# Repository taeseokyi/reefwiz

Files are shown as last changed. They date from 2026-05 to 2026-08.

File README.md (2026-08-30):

# AquaWiz - 고정밀 pH/dKH 자동 측정 시스템

🌐 **실시간 측정 그래프:** https://taeseokyi.github.io/reefwiz/
(안드로이드 Chrome에서 열어 메뉴 → **홈 화면에 추가**를 누르면 앱처럼 설치됩니다)

> **:warning: 경고:** 이 프로젝트의 하드웨어, 소프트웨어, 문서는 **어떠한 공식 검증도 거치지 않았습니다.** 측정 정확도, 전기적 안전성, 장기 신뢰성에 대한 보증이 없으며, 사용으로 발생하는 모든 결과(장비 손상, 생물 피해, 화재, 감전 등)에 대한 **책임은 전적으로 사용자 본인**에게 있습니다.

산호 수조(리프 탱크)를 위한 Arduino Nano 기반 **자동 경도(dKH) 측정기**입니다.
탄산염 화학법을 이용하여 참조 해수와 수조수의 pH 차이로부터 dKH를 자동 산출합니다.

셋팅 구성

### 최종 형태 — 밀폐 폐루프 (공통 헤드스페이스)

> **밀폐는 선택이 아니라 필수입니다.** 참조수 통·측정 챔버·펌프 흡입을 **하나의 밀폐된 공기**로 묶어, 측정 순간 참조수(ref)와 수조수(tank)가 **같은 pCO₂**를 공유하도록 보장합니다. 이것이 방 CO₂ 변동을 차동으로 상쇄하는 핵심 조건이며, 동시에 증발(경도 농축)까지 차단합니다. 밀폐 적용 후 첫 새벽(고-CO₂) 측정에서 그간 재현되던 새벽 오차가 사라졌습니다(ΔpH −0.043 → **−0.008**) — [측정 대장](docs/measurement-ledger.md) 2026-06-19 참조.

| 제어기 |
|:---:|
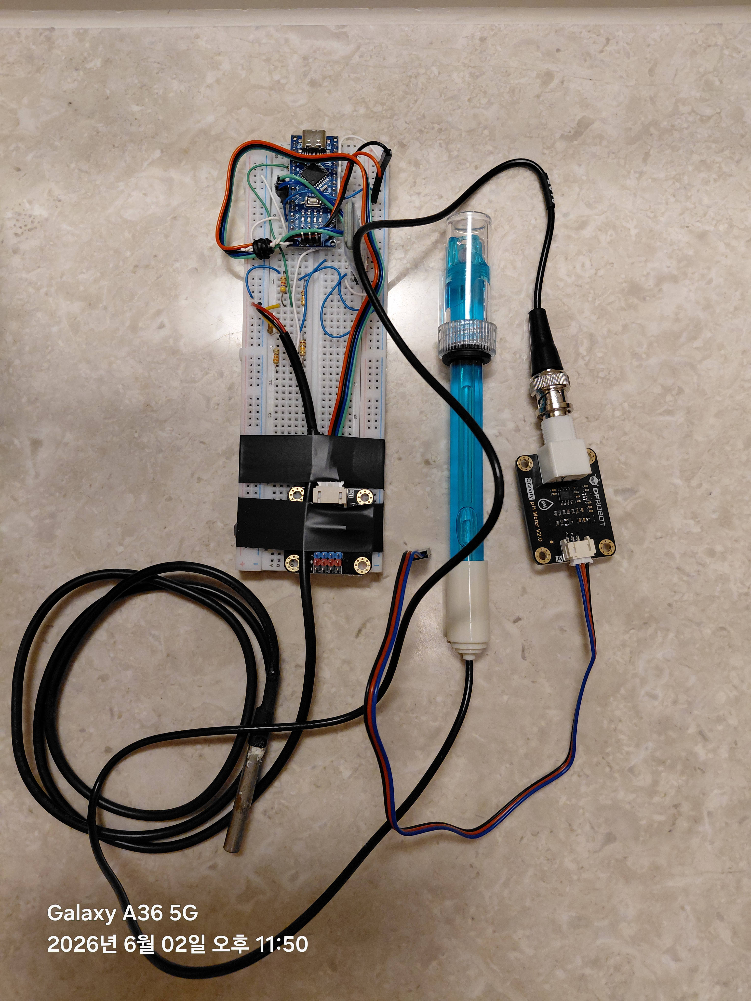
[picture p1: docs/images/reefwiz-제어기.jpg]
|  |

### 주요 특징

- **[±0.07 dKH 정확도](docs/system-setup.md#측정-정확도)** — 16비트 ADC + 64회 오버샘플링 + Nernst 온도 보정, 분해능 ±0.001 dKH
- **[PC 연동 평형 자동 측정](docs/system-setup.md#자동-측정-시퀀스-pc-측-v4)** — 샘플링 → 폭기(CO2 평형) → tank·ref **진짜 평형(평탄)까지** pH 측정 → dKH 계산 → 정리. 펌웨어가 아닌 PC측 파이썬 스크립트가 평탄(수렴) 판정으로 단계를 제어
- **[탄산염 화학법](#측정-원리)** — `KH_tank = KH_ref × 10^(-ΔpH)`, 참조수와 동시 탈기로 CO2 변수 제거
- **[Nernst 온도 보정](docs/system-setup.md#nernst-온도-보정)** — 보정 온도 EEPROM 저장, 15~35°C 전 범위 오차 0%
- **[블루투스 제어](docs/user-manual.md#14-블루투스-터미널-앱)** — HC-06으로 스마트폰에서 원격 제어/모니터링 ( <a href="https://play.google.com/store/apps/details?id=de.kai_morich.serial_bluetooth_terminal" target="_blank">Serial Bluetooth Terminal</a> 앱 추천)
- **[참조 dKH 역산](docs/user-manual.md#35-calref--참조-dkh-역산)** — 수조 dKH 실측값으로 참조수 dKH를 자동 계산, 참조수 별도 측정 불필요
- **[밀폐 공통 헤드스페이스 (필수)](docs/system-setup.md#위즈-탱크)** — 참조수·측정수·펌프 흡입이 한 밀폐 공기를 공유 → 측정 순간 ref·tank pCO₂ 일치(방 CO₂ 공통모드 상쇄) + 증발/오염 차단. 새벽 고-CO₂에서도 ΔpH 안정(2026-06-19 검증)
- **[3D 프린팅 하우징](docs/system-setup.md#하우징-3d-프린팅)** — OpenSCAD 파라메트릭 설계, 부품 실측 후 즉시 출력
- **[웹 대시보드 (PWA)](docs/user-manual.md#9-웹-대시보드)** — 측정 완료 직후 결과가 자동으로 GitHub Pages에 반영. dKH 그래프(3일/7일/전체), 평탄 수렴 곡선 조회(최근 14일), 최신값 JSON API
- **[도저 자동 조정 (권고)](docs/user-manual.md#10-도저-자동-조정-올포리프)** — 측정된 dKH 수준(3회 중앙값)·추세(7일 기울기)로 올포리프 도징량 조정을 계산. 대시보드에서 수동 도징량·목표 dKH 설정 가능
- **[reefCore 연동](docs/reefcore-integration.md)** — 측정값을 reefCore 생태계(reefChecker)에 측정 레코드로 발행(수동 도구 `bin/reefcore_bridge.py`. 측정 스크립트의 자동 발행은 2026-08-12 제거)
- **확장 가능** — ESP32 보드와 시리얼/블루투스 연결로 Wi-Fi, 모바일 앱, 인터넷 접속으로 확장 가능

> 정밀한 pH 측정을 위해 Wi-Fi가 없는 Arduino Nano를 사용하여 전자기 간섭을 최소화하였습니다. Wi-Fi, 웹 대시보드, 데이터 로깅 등 부족한 기능은 ESP32를 시리얼/블루투스로 연결하면 해결 가능합니다.

> 연동 펌프의 토출량은 설정한 시간(초)에 비례하지만, 호스 길이나 수두차에 따라 실제 물량이 달라질 수 있습니다. 각 펌프에 PWM 속도 컨트롤러의 Motor− 출력을 L298N ENA/ENB에 연결하여 역 PWM으로 모터 속도를 제어하므로, 토출량을 미세하게 조정할 수 있습니다.

## 한눈에 보기

| 시스템 구성도 | 호스 연결도 |
|:---:|:---:|
| 구성도 | 호스 |

| 회로도 (Fritzing) | 하우징 (3D 프린팅) |
|:---:|:---:|
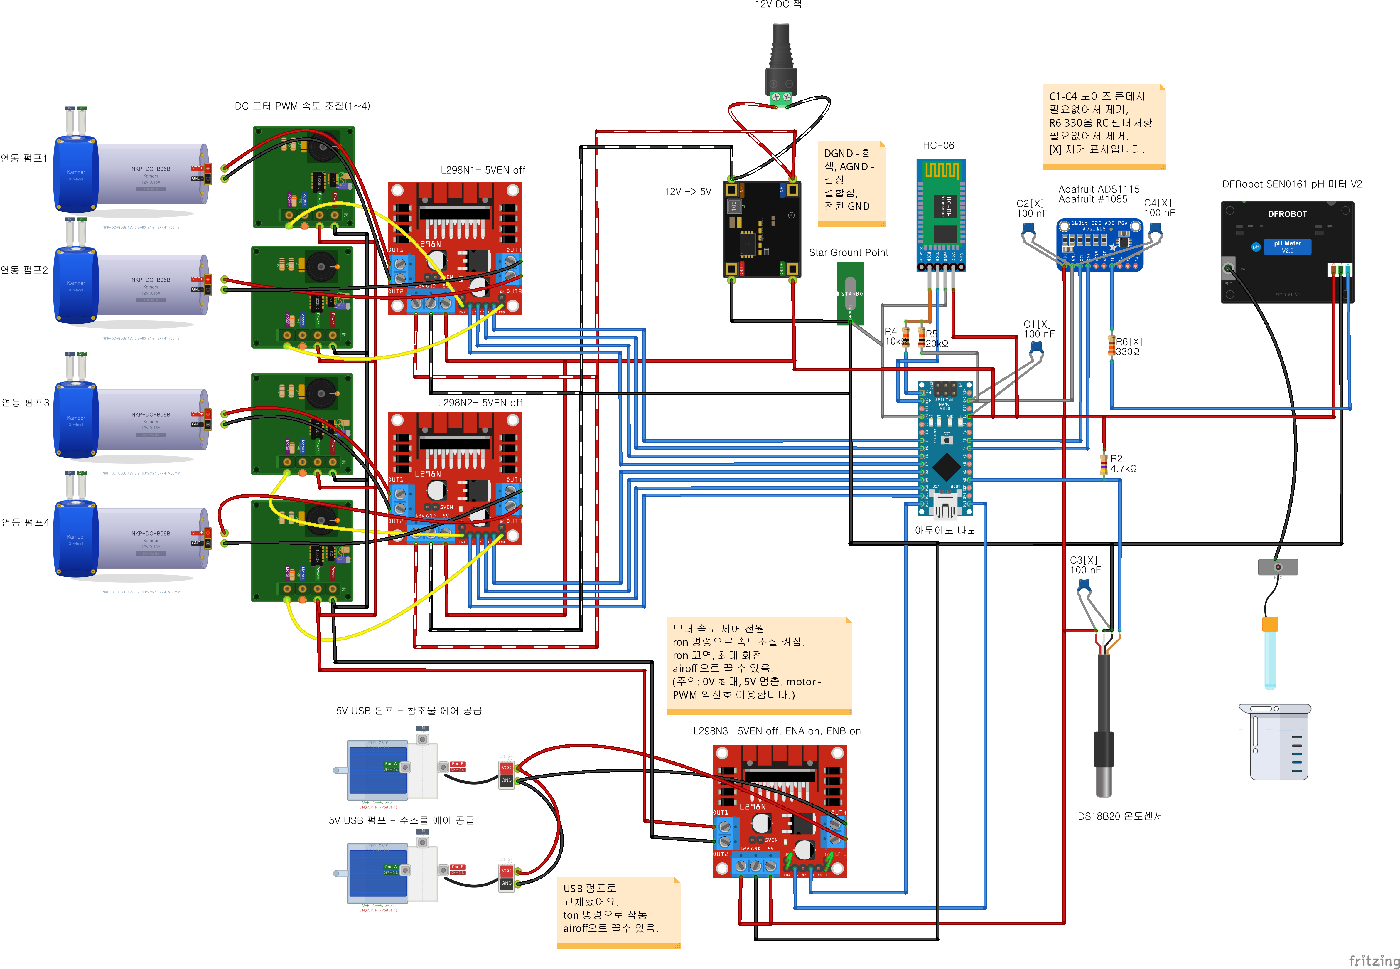
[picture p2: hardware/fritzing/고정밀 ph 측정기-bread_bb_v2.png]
회로도
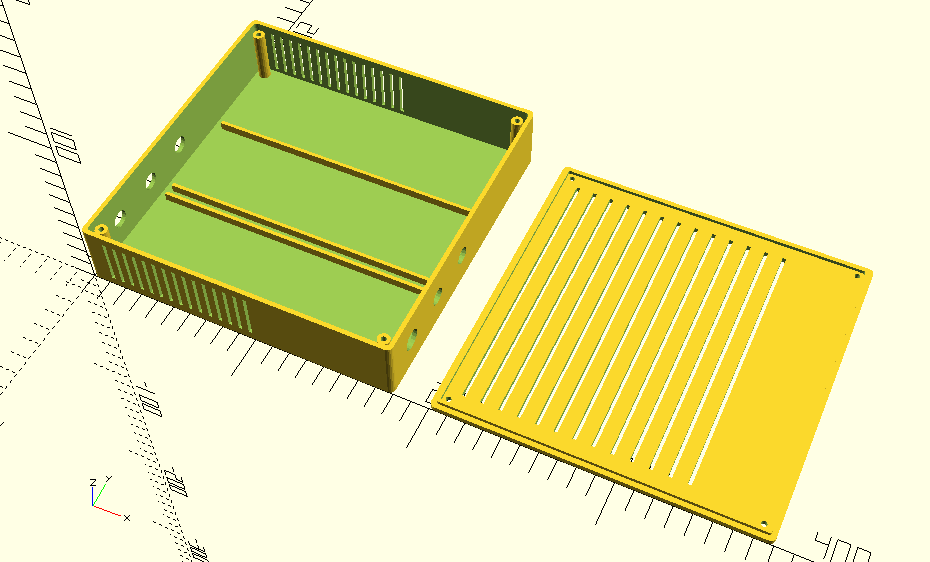
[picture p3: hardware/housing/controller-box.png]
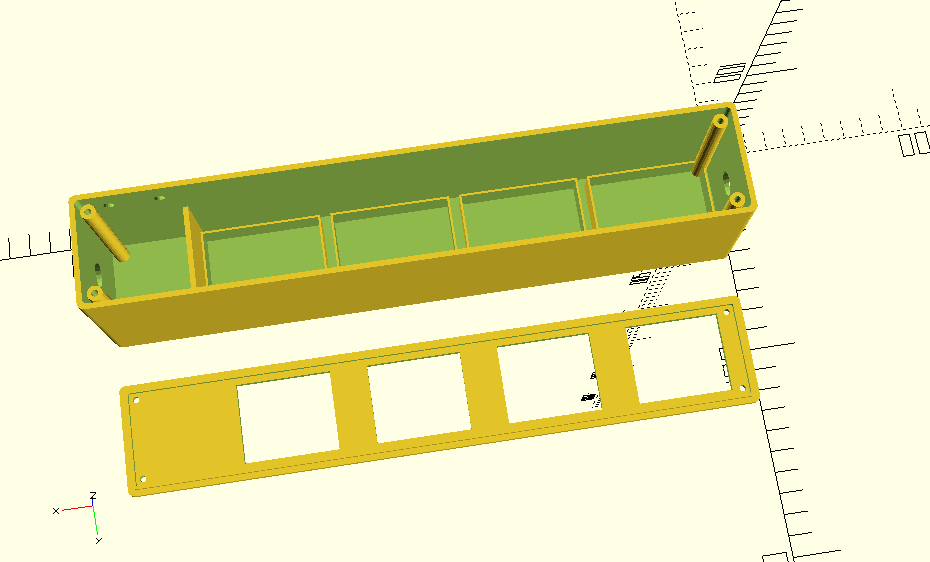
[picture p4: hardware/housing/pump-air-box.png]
펌프
|  |   |

## 측정 정확도

> **dKH 8.5 기준, 시스템 정확도 ±0.07 dKH (±1.2%)** — pH 프로브 반복성이 전체 오차의 97%를 차지하며, 전자 회로와 펌웨어 계산 로직은 프로브 성능을 100% 활용할 수 있는 수준입니다.

| 항목 | 성능 | 핵심 기술 |
|---|---|---|
| 측정 분해능 | **±0.001 dKH** | 16비트 ADC (ADS1115) + 64샘플 트림평균(정렬 후 상·하위 16개 버리고 중앙 32개 평균 → 폭기 버블 스파이크 제거) |
| 시스템 정확도 | **±0.07 dKH (±1.2%)** | Nernst 보정 + 동일 온도 차등 측정 |
| 온도 보정 오차 | **0%** | 보정 온도 EEPROM 저장, 15~35°C 전 범위 |

[상세 오차 분석 →](docs/system-setup.md#오차-요인-분석-dkh-85-기준)

> **이 수치는 책상 계산이 아니라 수십 회의 실측·검증을 거쳐 다듬은 결과입니다.** 코드 버전(V0~V4)별 측정 기록, 환경 변수(방 CO₂) 통제, 차동 측정이 방 CO₂ 의존성을 제거함을 보인 ΔpH 검증, 그리고 그 해석을 뒷받침한 학술 문헌까지 — 신뢰성의 근거는 모두 [**측정 대장**](docs/measurement-ledger.md)에 시각순으로 정리되어 있습니다.

> **✅ 완전 널테스트로 확정 (2026-06-21):** 같은 물(위즈 해수)을 ref·tank 양쪽에 넣어 *물 차이를 0으로 만든* 완전 널에서 **ΔpH −0.003, dKH 8.387 (참값 8.448 대비 오차 −0.061)** 을 측정했습니다. 물 차이가 구성상 0이므로 이 −0.06 dKH가 계측기의 *순수* 시스템 offset입니다 — ±0.07 정확도 사양을 실측으로 뒷받침합니다. (참고: 측정 시점에 보였던 큰 오차는 *시험용 옛 200mL 시료 물의 알칼리니티 손실(CaCO₃ 석출)* 이었으며 계측기 오차가 아니었습니다. 신선한 물에선 무보정으로 ±0.1 dKH 안.) — [측정 대장 최종 결론](docs/measurement-ledger.md) 참조.

## 측정 원리

```
KH_tank = KH_ref × 10^(-ΔpH)
ΔpH = pH_ref − pH_tank
```

탈기 후 두 샘플의 CO2 농도가 동일해지면, pH 차이는 순수하게 알칼리니티(dKH) 차이만을 반영합니다.

> **★전제 = 같은 pCO₂.** 위 식은 측정 순간 ref·tank의 CO₂가 동일할 때만 순수 dKH차를 줍니다. 이를 보장하는 것이 **밀폐 공통 헤드스페이스**입니다 — 두 물이 하나의 밀폐 공기를 공유하므로 방 CO₂가 변해도 공통모드로 상쇄됩니다. 밀폐는 [위즈 탱크 구성](docs/system-setup.md#위즈-탱크)에서 **필수**로 다룹니다.

## 하드웨어

| 부품 | 모델 | 역할 |
|---|---|---|
| MCU | Arduino Nano V3.0 (ATmega328P) | 메인 컨트롤러 |
| pH 센서 | DFRobot SEN0161-V2 | pH 전압 측정 |
| ADC | Adafruit ADS1115 (16-bit) | I2C 고정밀 ADC |
| 온도 센서 | DS18B20 (PTFE) | Nernst 온도 보상 |
| 블루투스 | HC-06 | 하드웨어 Serial (9600 baud) |
| 모터 드라이버 | L298N x 3 | L298N1/N2: 도징 펌프 (12V), L298N3: 에어 펌프 (5V) |
| 도징 펌프 | Kamoer NKP-DC-B06S x 4 | 참조수/수조수 도징 |
| 에어 펌프 | USB 5V 에어 펌프 x 2 | 참조수/수조수 폭기 (L298N3 제어) |
| 전원 | 12V DC + Buck Converter (5V) | 전원 공급 |

- 구매 링크 포함 상세 목록: [준비물 목록](docs/parts-list.md)
- 구성 요소 상세 / 펌프 역할: [자동화 환경 구성 — 구성 요소](docs/system-setup.md#구성-요소)
- 3D 프린팅 하우징: [자동화 환경 구성 — 하우징](docs/system-setup.md#하우징-3d-프린팅)

### 회로도

브레드보드 회로도

Fritzing 소스: <a href="hardware/fritzing/고정밀%20ph%20측정기-bread.fzz" target="_blank">고정밀 ph 측정기-bread.fzz</a> | PDF: <a href="hardware/fritzing/고정밀%20ph%20측정기-bread_bb.pdf" target="_blank">브레드보드 도면</a>

**핀 배치 요약:**

```
D0  (RX)  ← HC-06 TX        D1  (TX)  → HC-06 RX (전압분배기)
D4~D7     → L298N1 IN1~IN4  D8~D11    → L298N2 IN1~IN4
D12       → L298N3 IN2 (에어 펌프 ON/OFF, ron/roff)  D13  → L298N3 IN4 (PWM 속도 제어기 ON/OFF, ton/toff)
A0  (D14) ← DS18B20 DQ      A4/A5     ↔ ADS1115 I2C
```

### 전원 / 접지

```
12V DC Jack
  ├── L298N1, L298N2 (모터 전원, 12V → 도징 펌프)
  ├── Buck 12V→5V (Arduino, ADS1115, HC-06)
  └── USB 5V → L298N3 (에어 펌프 제어)
속도 제어: PWM 컨트롤러 Motor− → L298N ENA/ENB (역 PWM)
접지: Star Ground Point (DGND/AGND 분리 후 한 점 결합)
```

## 빌드 및 업로드

| 라이브러리 | 제작자 |
|---|---|
| DFRobot_PH | DFRobot |
| Adafruit ADS1X15 | Adafruit |
| OneWire | Paul Stoffregen |
| DallasTemperature | Miles Burton |

1. Arduino IDE에서 [`firmware/reefwiz_meter_m1/reefwiz_meter_m1.ino`](firmware/reefwiz_meter_m1/reefwiz_meter_m1.ino) 열기
2. 보드: **Arduino Nano**, 프로세서: **ATmega328P** 선택
3. **HC-06을 D0/D1에서 분리** 후 업로드 → 완료 후 재연결

## 사용 방법

### 초기 설정

```
1. pH 2점 보정:   enterph → calph (pH7) → exitph → enterph → calph (pH4) → exitph
2. 온도 오프셋:   settemp:-0.3
3. 참조 dKH:      setref:8.5
```

### 자동 측정 (PC 연동)

측정 전 고정 사전폭기(tank 25분·ref 3.5분)로 시료를 평형 근처까지 올린 뒤 **tank·ref가 진짜 평형(평탄)에 도달할 때까지** 반복 측정해야 하므로(평탄 판정 = 측정값 비교 후 반복 결정, 기포기 모터 노이즈 차단을 위해 각 read 직전에만 폭기를 끔), 자동화는 펌웨어가 아닌 **PC측 파이썬 스크립트**가 담당합니다. 펌웨어에는 더 이상 `seq` 매크로가 없습니다.

```bash
# 1회 측정 후 종료 (Windows 작업 스케줄러 정시 호출용 / 수동 실행 가능)
python bin/measure_kh_once.py        # 포트 미지정 시 bt_config.json 의 measure 포트 사용
python bin/measure_kh_once.py COM7   # 포트 직접 지정
```

스크립트는 준비(샘플링·헹굼) → **[A] tank 사전폭기(25분) + tank 평탄까지** → 전이 → **[B] ref 사전폭기(3.5분) + ref 평탄까지** → `calkh` → 정리 순으로 펌웨어 명령을 단계별 전송합니다. 상세 흐름·상수·스케줄러 등록은 [자동화 환경 구성 — 자동 측정 시퀀스](docs/system-setup.md#자동-측정-시퀀스-pc-측-v4)를 참조하세요.

### 주요 명령어

| 분류 | 명령어 |
|---|---|
| pH 측정 | `ref`, `tank`, `calkh`, `calref`, `status`, `khhist` |
| 식별 | `ver` (기기 버전 한 줄: `ReefWiz Meter M-1 v1.0.0 #커밋코드`) |
| pH 보정 | `enterph`, `calph`, `exitph` |
| 설정 | `settime:HH`, `setref:x`, `settemp:x` |
| 모터 | `m1f:초`, `m1b:초`, `m1s` (m1~m4) |
| 에어/PWM | `ron`/`roff` (D12 에어 ON/OFF), `ton`/`toff` (D13 PWM 제어기 ON/OFF), `airoff` (둘 다 OFF) |
| 정지 | `m1s`~`m4s` (개별), `stop` (전체 모터+핀 OFF) |

전체 명령어 및 상세 설명은 [사용 설명서](docs/user-manual.md)를 참조하세요.

## 문서

| 문서 | 설명 |
|---|---|
| [자동화 환경 구성](docs/system-setup.md) | 구성 요소, 호스 연결, 측정 시퀀스, 동기화 파이프라인, 하우징 |
| [사용 설명서](docs/user-manual.md) | 전체 명령어, 보정, 오류 메시지, 웹 대시보드, 도저 자동 조정 |
| [준비물 목록](docs/parts-list.md) | 부품 사진, 구매 링크, 금액 |
| [**측정 대장**](docs/measurement-ledger.md) | 코드 버전별 실측 기록·환경·ΔpH 검증·참조 문헌 — **결과 신뢰성의 근거** |
| [reefCore 연동](docs/reefcore-integration.md) | 측정값을 reefCore 생태계에 발행하는 MQTT 연동(수동 브리지) |
| [블루투스 재연결](docs/bt-reconnect-and-testing.md) | HC-06 RF 순단 대응·장기 사망 보강·시뮬레이터 회귀 검증 |

## 산호 수조 권장 dKH 범위

| 유형 | dKH |
|---|-----|
| 자연 해수 | 6.5 ~ 7.5 |
| 산호 수조 권장 | 8 ~ 12 |
| SPS 경산호 최적 | 8 ~ 9 |
| LPS/소프트 코랄 | 7 ~ 11 |

## 라이선스

이 프로젝트는 개인 용도로 제작되었습니다.

---

이 프로젝트의 펌웨어, 문서, 다이어그램, 하우징 설계의 **80% 이상이 AI의 도움**을 받아 작성되었습니다.

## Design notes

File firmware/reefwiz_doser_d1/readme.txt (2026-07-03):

L298N DC 모터 드라이버 - PWM 제어 하지 않음

상황 :   24V 전원에  6V 모터를 사용.   ENA, motor1, 오른쪽

“L298N 칩 자체는 ENA로 PWM 제어가 가능하지만,
시중 모듈 보드의 ENA 회로는 LED·저항이 RC 필터처럼 작동해 PWM 신호가 흐려집니다.
따라서 실제로는 IN1/IN2에 PWM을 걸어야 동작하며,
이때 BJT의 높은 포화전압과 24V 저듀티 구동으로 발열이 심해집니다.”

결론, PWM 을 쓰지 않고, L298N  출력쪽에 out1,out2 추가로 적정 볼륨형 PWM DC 모터 제어기를 추가 한다.

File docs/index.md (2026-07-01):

# AquaWiz

산호 수조용 고정밀 pH/dKH 자동 측정기 문서 모음입니다. 전체 개요는 [프로젝트 README](https://github.com/taeseokyi/reefwiz#readme)를 먼저 보세요.

## dKH 측정 대장 — 실시간 그래프

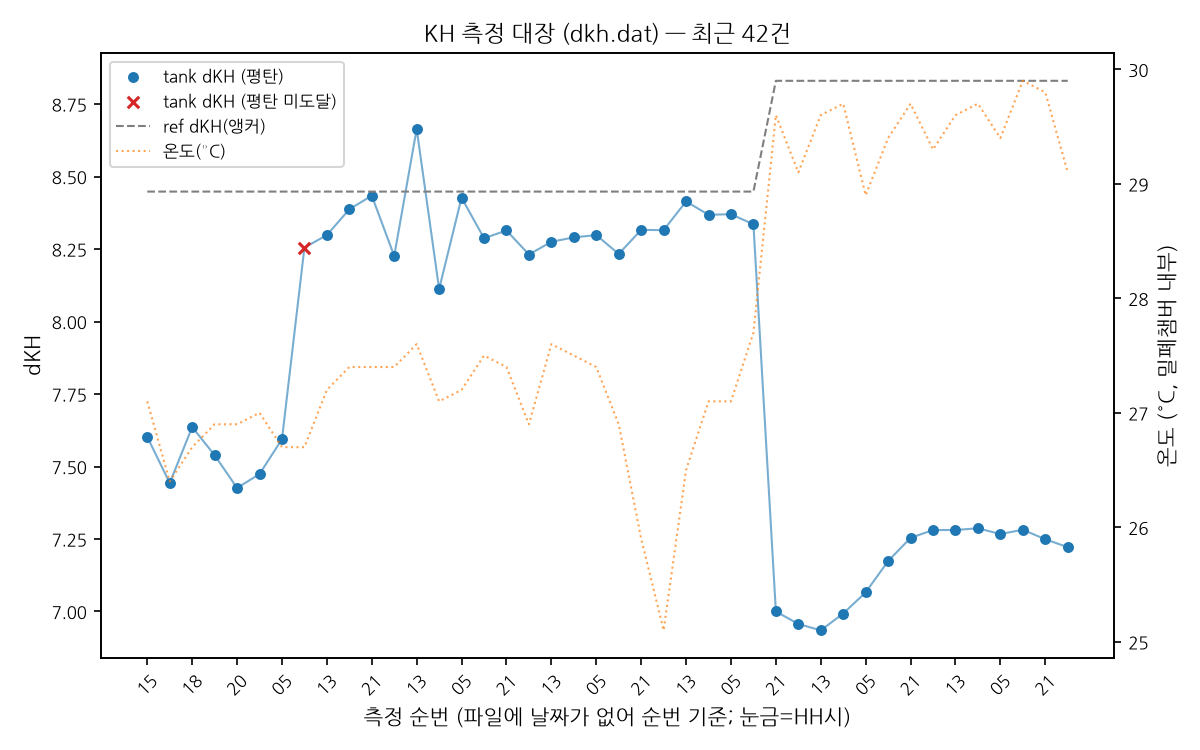
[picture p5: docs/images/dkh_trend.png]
dKH 추세


하루 3회(05/13/21시) 측정 결과가 자동으로 반영됩니다. 상세 기록·검증 근거는 [측정 대장](measurement-ledger.md)에 있습니다.

## 문서

- [측정 대장](measurement-ledger.md) — 코드 버전별 실측 기록·환경·ΔpH 검증·참조 문헌
- [사용 설명서](user-manual.md)
- [자동화 환경 구성](system-setup.md)
- [준비물 목록](parts-list.md)
- [reefCore 연동](reefcore-integration.md)
- [블루투스 재연결/테스트](bt-reconnect-and-testing.md)
- [연구 노트 모음](notes/README.md)

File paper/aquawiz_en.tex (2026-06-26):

\documentclass[11pt]{article}

% ---- arXiv-style preprint layout (pdflatex) ----
\usepackage[utf8]{inputenc}
\usepackage[T1]{fontenc}
\usepackage{lmodern}
\usepackage[margin=1in]{geometry}
\usepackage{amsmath,amssymb}
\usepackage{graphicx}
\usepackage{booktabs}
\usepackage{array}
\usepackage{multirow}
\usepackage{longtable}
\usepackage{caption}
\usepackage{authblk}
\usepackage{xcolor}
\usepackage{enumitem}
\usepackage[hidelinks]{hyperref}
\usepackage{textcomp}
\usepackage{mhchem}
\usepackage{siunitx}
\sisetup{detect-all}
\usepackage{pgfplots}
\pgfplotsset{compat=1.15}
\usetikzlibrary{arrows.meta,positioning,calc}

\captionsetup{font=small,labelfont=bf}
\renewcommand{\arraystretch}{1.15}

% convenience macros
\newcommand{\dpH}{\ensuremath{\Delta\mathrm{pH}}}
\newcommand{\dkh}{\ensuremath{\,\mathrm{dKH}}}
\newcommand{\co}{\ensuremath{\mathrm{CO_2}}}
\newcommand{\pco}{\ensuremath{p_{\mathrm{CO_2}}}}
\newcommand{\at}{\ensuremath{A_\mathrm{T}}}

\title{\bfseries A Low-Cost Single-Probe Differential-pH Aeration Monitor for\\
Seawater Carbonate Alkalinity: Systematic-Error Decomposition and\\
Sub-0.25\,dKH Accuracy via Sealed Common-Headspace Equilibration}

\author[1]{nowforyou\thanks{Correspondence: \texttt{taeseokyi@gmail.com}}}
\affil[1]{REEF FAMILY}

\date{\today}

\begin{document}
\maketitle

\begin{abstract}
\noindent
Carbonate alkalinity (``KH'', expressed in degrees, \dkh) is the single most
control-critical water-chemistry parameter in reef aquaria, yet affordable
continuous monitors are scarce and reagent titration is laborious. We describe
an open, reagent-free monitor that infers alkalinity from the equilibrium pH a
seawater sample reaches after aeration to atmospheric \co{}, using a
\emph{single} pH probe to measure an aquarium sample (``tank'') and a
known-alkalinity reference (``ref'') in immediate succession. Because dKH is
computed from the pH \emph{difference}
($\mathrm{KH_{tank}} = \mathrm{KH_{ref}}\cdot 10^{\dpH}$), absolute probe drift
and room-\co{} excursions are common-mode signals that cancel. Over a
nine-day instrumented campaign (30 logged measurements across five
firmware/method revisions) we observed a persistent uncorrected error of
$-0.92\dkh$ and, rather than zero-point calibrating it away, decomposed it.
Three interventions---(i) plateau-following measurement to true gas
equilibrium, (ii) a single \emph{sealed common headspace} shared by sample,
reference and pump intake, and (iii) an actively aerated 5\,L reference anchor
that pins the headspace \pco{}---collapsed the dawn-\co{} error and the
diurnal evaporation confound, and shrank measurement scatter to
$\mathrm{SD}=\pm0.08\dkh$ (about one-third of the $\pm0.25\dkh$ design goal). A
sequence of null experiments (identical water in both vessels, true
$\dpH=0$) then localized the residual: a \emph{complete null} returned
$\dpH=-0.003$, $\mathrm{dKH}=8.387$, i.e.\ an instrument offset of only
$-0.06\dkh$. The remaining $-0.86\dkh$ was traced to alkalinity loss
(\co{}\,driven \ce{CaCO3} precipitation / biofilm) in the days-old, small,
open tank aliquot---a sample-handling artifact, not a measurement fault.
Re-running the null on the same aged aliquot over the following day showed the
offset drifting away from zero ($-0.22$ then $+0.22\dkh$ on successive runs) with
the electronics untouched, confirming the attribution in the time domain.
The instrument therefore meets the $\pm0.25\dkh$ goal uncorrected, with
zero-point calibration deemed unnecessary. Our independently obtained error
structure (room-\co{} sensitivity, bubble-quality dependence, sealing as the
remedy) reproduces the published behaviour of a commercial counterpart, providing
external validation of both the diagnosis and the remedy.
\end{abstract}

\noindent\textbf{Keywords:} reef aquarium; carbonate alkalinity; total
alkalinity; \co{} equilibration; differential pH; low-cost instrumentation;
common-mode rejection; \ce{CaCO3} precipitation.

% =====================================================================
\section{Introduction}
% =====================================================================
Stony corals and other calcifying reef organisms deposit calcium carbonate at
a rate that continuously consumes carbonate alkalinity. In a closed reef
aquarium the resulting alkalinity drawdown is fast (often
$0.5$--$1.5\dkh\,\mathrm{day^{-1}}$) and swings of more than $\sim1\dkh$ are
implicated in coral tissue stress. Alkalinity (\at{}, conventionally reported
by hobbyists as ``KH'' in German degrees, $1\dkh \approx
0.357\,\mathrm{meq\,L^{-1}}$) is therefore the parameter most worth measuring
\emph{often}.

The accessible options are unsatisfying for continuous use. Manual reagent
titration (e.g.\ commercial drop kits) is accurate but labour-intensive and
discrete. Colorimetric robots automate titration but consume reagent and are
expensive. Direct potentiometric pH alone is \emph{not} an alkalinity measurement,
because seawater pH depends jointly on \at{} and \pco{}, and aquarium \pco{}
varies strongly over the day (room ventilation, photosynthesis, respiration).

A reagent-free alternative exploits the fact that if a sample is aerated until
its \pco{} equilibrates with the surrounding air, the equilibrium pH becomes a
single-valued function of alkalinity at fixed temperature and salinity. A
commercial product (AquaWiz) is built on this principle and is used by reef
hobbyists, but community reports document recurring inaccuracy tied to room-\co{}
fluctuation and to aeration/bubble quality. The contribution of this paper is
not the principle but a \emph{quantitative diagnosis}: starting from a working
DIY build, we conduct a nine-day instrumented campaign, expose a $-0.92\dkh$ raw error,
and show by construction (null experiments) that essentially all of it is a
sample-handling artifact rather than an instrument limitation---reducing the
true instrument offset to $-0.06\dkh$ and meeting a $\pm0.25\dkh$ goal without
calibration. Along the way we establish a small set of design rules (sealed
common headspace; plateau-following to true equilibrium; an actively aerated
reference anchor; a two-gate plateau criterion) that we expect to generalize to
any single-probe differential-pH alkalinity monitor.

% =====================================================================
\section{Measurement Principle}\label{sec:principle}
% =====================================================================

\subsection{Aeration makes equilibrium pH a proxy for alkalinity}
At fixed temperature $T$ and salinity $S$, the seawater carbonate system has
two degrees of freedom; fixing any two of
$\{\at{}, \mathrm{DIC}, \pco{}, \mathrm{pH}\}$ determines the rest. Aeration with
a large excess of room air drives the dissolved \co{} toward Henry's-law
equilibrium with the gas phase, $[\co{}]_{aq}=K_H\,\pco{}$, so that
$\pco{}(\mathrm{water}) \to \pco{}(\mathrm{air})$. Once \pco{} is clamped by the
atmosphere, the equilibrium pH is a single-valued function of alkalinity:
\begin{equation}
\mathrm{pH_{eq}} = f(\at{},\,\pco{},\,T,\,S).
\label{eq:pheq}
\end{equation}
With \pco{}, $T$, $S$ held common, the \emph{only} variable that can move
$\mathrm{pH_{eq}}$ is \at{}. Measured equilibrium pH is therefore a proxy for
alkalinity.

\subsection{Why the differential cancels room \co{}}
The instrument never relies on the absolute value of \pco{}. It aerates the
reference and the tank sample to the \emph{same} atmospheric ceiling (in the
final design, by aerating both against one shared headspace simultaneously,
Sec.~\ref{sec:methods}) and reports the \emph{difference} of their equilibrium
pH. Because the absolute \pco{} term is common to both samples, it cancels in
the difference: a room-\co{} excursion is a common-mode signal that drops out.
What survives the subtraction is the true alkalinity difference plus electrode
noise ($\pm0.005$--$0.01$\,pH). This is the central robustness argument of the
method, and the reason a \emph{single} probe (rather than two matched probes)
is used: a single sensor's slow asymmetry-potential and reference-junction
drift load identically onto both readings and cancel in \dpH{}.

\subsection{Over-aeration is impossible; only \emph{insufficient} aeration errs}
Equation~\eqref{eq:pheq} has a hard ceiling at $\pco{}(\mathrm{air})$: once the
water reaches atmospheric equilibrium, further aeration cannot raise pH. There
is consequently no ``over-aeration'' failure mode. Error enters only through
\emph{insufficiency}: if residual \co{} remains in one vessel, that side's pH is
unfairly depressed and a spurious \dpH{} appears. The differential's assumption
is precisely that ref and tank share the same \pco{}; broken symmetry breaks
the cancellation. This motivates measuring to a genuine plateau rather than for
a fixed time (Sec.~\ref{sec:methods}).

\subsection{Volume independence at full equilibrium}
Equation~\eqref{eq:pheq} contains no volume term (Henry's law is
intensive). Hence even a large volume mismatch---in our final null,
$100\,\mathrm{mL}$ of tank water against a $5\,\mathrm{L}$ reference---produces
\emph{zero} differential error provided both vessels reach \emph{full}
equilibrium. The familiar ``equal volumes for symmetry'' rule applies only
under \emph{partial} equilibration, where unequal volumes sit at different
points on the first-order approach curve
$C(t)-C^\ast = (C_0-C^\ast)\,e^{-t/\tau}$. The true requirements are just
(a) both fully equilibrated and (b) matched \pco{} and $T$. The larger volume
is rate-limiting, with a time constant
\begin{equation}
\tau \;\propto\; \frac{V}{K_H\,Q_\mathrm{gas}}\,\beta
\;\sim\; \frac{1}{\mathrm{VVM}}\,\beta,
\label{eq:tau}
\end{equation}
where $\mathrm{VVM}=Q_\mathrm{gas}/V$ is gas volume per liquid volume per
minute and $\beta$ is a seawater chemical factor (only trace
$[\co{}]_{aq}$ is strippable; the Revelle buffering raises $\tau$ by
$\sim8$--$15\times$). Equation~\eqref{eq:tau} is the basis for the
``increase aeration to shorten the measurement'' lever discussed later, and for
the choice to miniaturize the rate-limiting reference.

\subsection{The differential dKH formula}
The firmware (Arduino Nano / ATmega328P; pH via DFRobot Gravity probe + ADS1115
16-bit ADC) digitizes one probe, reading reference then tank pH, and computes
\begin{equation}
\boxed{\;\mathrm{KH_{tank}} \;=\; \mathrm{KH_{ref}}\cdot 10^{-(\mathrm{pH_{ref}}-\mathrm{pH_{tank}})}
\;=\; \mathrm{KH_{ref}}\cdot 10^{\dpH}\;}
\label{eq:dkh}
\end{equation}
with $\dpH \equiv \mathrm{pH_{tank}}-\mathrm{pH_{ref}}$ and
$\mathrm{KH_{ref}}=8.448\dkh$ an EEPROM-stored \emph{anchor} constant (set by a
\texttt{calref} command after evaporation top-off; \emph{not} a per-run
measurement---this is why the reference column reads a constant 8.448 in every
log line). Equation~\eqref{eq:dkh} depends only on \dpH{}; absolute pH cancels
exactly. Differentiating,
\begin{equation}
\frac{d\,\mathrm{KH_{tank}}}{d\,\dpH}\bigg|_{\dpH=0}
= \mathrm{KH_{ref}}\ln 10 \approx 19.45\;\dkh\,\mathrm{pH^{-1}},
\label{eq:sens}
\end{equation}
i.e.\ $0.01$\,pH of uncancelled difference maps to $\approx0.19\dkh$. This high
sensitivity is what makes both the cancellation and the plateau criterion
matter. Temperature compensation is applied per reading by a Nernst relation
$\mathrm{pH_{corr}}=7.0+(\mathrm{pH_{raw}}-7.0)\,(273.15+T_\mathrm{cal})/(273.15+T_\mathrm{meas})$,
nominally zero-error over 15--35\,\textcelsius. Each pH reading is a trimmed
mean of 64 samples (discard the top and bottom 16, average the middle 32) to
reject aeration-bubble spikes.

% =====================================================================
\section{Apparatus}\label{sec:apparatus}
% =====================================================================
The build (Table~\ref{tab:bom}, Fig.~\ref{fig:device}) is a closed fluidic loop
around four bidirectional peristaltic pumps, two USB air pumps, a single pH
probe, and a 1-Wire temperature sensor, all driven by an Arduino Nano over a
9600-baud Bluetooth (HC-06) serial link to a host PC.

\begin{figure}[t]
\centering
\begin{tikzpicture}[
  font=\footnotesize, >={Latex[length=1.8mm]},
  vessel/.style={draw, rounded corners=2pt, fill=blue!6, align=center},
  pump/.style={draw, circle, fill=yellow!35, font=\scriptsize\bfseries, inner sep=0.4pt, minimum size=5.5mm},
  flow/.style={<->, thick, blue!55!black},
  air/.style={-{Latex[length=1.6mm]}, densely dotted, red!65!black, thick},
  wire/.style={-{Latex[length=1.6mm]}, gray!55!black},
]
% sealed headspace
\draw[dashed, rounded corners=7pt, gray!65, line width=0.9pt] (0.1,-3.05) rectangle (10.9,1.95);
\node[anchor=north east, gray!55!black, font=\scriptsize] at (10.8,1.88) {Sealed common headspace ($\approx$4\,L)};
% controller (outside, top)
\node[draw, rounded corners=2pt, fill=gray!10, align=center] (mcu) at (4.9,2.75)
  {Arduino Nano $+$ HC-06\,/\,ADS1115 pH\,/\,DS18B20};
% vessels
\node[vessel, minimum width=15mm, minimum height=20mm, fill=cyan!10] (aq) at (-2.2,-0.6) {Main\\reef\\aquarium};
\node[vessel, minimum width=14mm, minimum height=14mm] (hold) at (1.9,0.7) {Holding};
\node[vessel, minimum width=21mm, minimum height=21mm] (meas) at (4.9,-0.7) {Measurement\\chamber};
\node[vessel, minimum width=16mm, minimum height=19mm] (ref) at (8.9,-0.4) {Reference\\1\,L\\\scriptsize($+T$ sensor)};
\node[vessel, minimum width=15mm, minimum height=11mm, fill=green!8] (kcl) at (4.9,-2.45) {3\,M KCl};
\node[draw, rounded corners=1pt, fill=red!9, font=\scriptsize, align=center] (airp) at (8.9,-2.45) {Air pumps (\texttt{ron})};
% pH probe
\draw[line width=1pt] ([xshift=-3mm]meas.north) -- ++(0,5mm) coordinate (pp);
\node[font=\scriptsize, anchor=south] at (pp) {pH probe};
% liquid flows with pumps
\draw[flow] (aq.east) -- (hold.west);
\node[pump] at ($(aq.east)!0.5!(hold.west)$) {M1};
\draw[flow] (hold.south) -- (meas.north west);
\node[pump] at ($(hold.south)!0.5!(meas.north west)$) {M2};
\draw[flow] (ref.west) -- (meas.east);
\node[pump] at ($(ref.west)!0.5!(meas.east)$) {M4};
\draw[flow] (kcl.north) -- (meas.south);
\node[pump] at ($(kcl.north)!0.5!(meas.south)$) {M3};
% air lines
\draw[air] (airp.north) -- (ref.south);
\draw[air] (airp.west) to[out=180,in=-90] (meas.south east);
% probe wire to controller
\draw[wire] (pp) to[out=90,in=-90] (mcu.south);
\end{tikzpicture}
\caption{Schematic of the sealed closed-loop monitor. A single pH probe in the
measurement chamber reads the tank aliquot and the reference in turn; four
bidirectional peristaltic pumps (M1--M4) move liquid between the main aquarium,
holding beaker, measurement chamber, reference reservoir, and KCl store; two air
pumps (\texttt{ron}) aerate the reference and the chamber simultaneously. The
reference, chambers and pump intakes share one sealed headspace ($\approx$4\,L),
so sample and reference see identical $p_{\mathrm{CO_2}}$ and evaporation is
suppressed; the controller sits outside. Between runs the probe rests in 3\,M
KCl (M3).}
\label{fig:device}
\end{figure}

\begin{table}[t]
\centering
\caption{Bill of materials (current build).}
\label{tab:bom}
\footnotesize
\begin{tabular}{@{}p{0.26\linewidth} p{0.50\linewidth} c@{}}
\toprule
Subsystem & Part & Qty \\
\midrule
Microcontroller & Arduino Nano V3.0 (ATmega328P) & 1 \\
pH probe & DFRobot Gravity pH V2 (SEN0161-V2), single glass electrode & 1 \\
ADC & DFRobot Gravity I\textsuperscript{2}C ADS1115 (16-bit) & 1 \\
Temperature & DS18B20 waterproof (1-Wire), in the 5\,L reference & 1 \\
Comms & HC-06 Bluetooth, 9600\,baud & 1 \\
Pumps & NKP-DC-B06B 12\,V peristaltic, bidirectional (M1--M4) & 4 \\
Motor drivers & L298 2\,A modules (2 for pumps, 1 for air) & 3 \\
Air pumps & USB 5\,V, switched together (\texttt{ron}) & 2 \\
Reference reservoir & 5\,L sealed container (``Wiz tank'') & 1 \\
Chambers & 200\,mL beakers: holding, measurement, 3\,M KCl & 3 \\
Probe storage & 3\,M KCl ($\approx$22\,\% w/v) & --- \\
\bottomrule
\end{tabular}
\end{table}

\paragraph{Fluidic topology (current).} All pumps are bidirectional
($\mathtt{f}$ = forward, $\mathtt{b}$ = reverse):
\begin{itemize}[nosep,leftmargin=1.4em]
\item \textbf{M1}: main aquarium $\leftrightarrow$ \emph{holding} beaker;
\item \textbf{M2}: holding $\leftrightarrow$ \emph{measurement} chamber;
\item \textbf{M3}: 3\,M KCl beaker $\leftrightarrow$ measurement chamber (probe soak / storage);
\item \textbf{M4}: 5\,L reference $\leftrightarrow$ measurement chamber.
\end{itemize}
Routing the tank sample through an intermediate holding beaker lets it be
temporarily \emph{parked} while the reference is measured, minimizing the
between-phase delay (Sec.~\ref{sec:methods}). Run times are encoded as the
integer in $\mathtt{mXf{:}NN}$ / $\mathtt{mXb{:}NN}$ (seconds); reverse runs
$\sim$8--10\,s longer than forward to fully clear the hose (current values
$\mathtt{m1f{:}70/m1b{:}82}$, $\mathtt{m2f{:}60/m2b{:}68}$,
$\mathtt{m3f{:}60/m3b{:}68}$, $\mathtt{m4f{:}60/m4b{:}70}$; the 5\,L hose is
longest, hence \texttt{m4b:70}).

\paragraph{Control commands.} Air and motor enables are independent lines:
\texttt{ron} turns \emph{both} air pumps on (used only while liquid is
stationary---bubble cleaning and measurement); \texttt{ton} enables the PWM
motor controller (\emph{required} before any pump will turn); \texttt{airoff}
drops both. A load-bearing invariant follows: because \texttt{airoff} also
disables the PWM controller, every liquid move must be preceded by
\texttt{airoff}\,$\rightarrow$\,\texttt{ton}; the last air command before a
motor must be \texttt{ton}. Measurement primitives are \texttt{tank} / \texttt{ref}
(sample and store one pH reading) and \texttt{calkh} (apply
Eq.~\eqref{eq:dkh}).

\paragraph{Sealed common headspace (required).} The 5\,L reference, the
measurement chamber, and the pump intake share \emph{one} sealed headspace.
This is not an optional refinement: it (i) guarantees tank and ref see identical
\pco{} at the instant of measurement (the differential's premise), (ii) blocks
room-\co{} excursions at the source, and (iii) suppresses evaporation. In the
final configuration the headspace is $\approx$4\,L, the reference $\approx$1\,L,
and the tank aliquot $100\,\mathrm{mL}$; an air stone placed \emph{in} the
reference actively pins the shared \pco{} within minutes (the
``anchor'', Sec.~\ref{sec:methods}). Separate or isolated headspaces are
explicitly forbidden---two headspaces drift independently and destroy the
cancellation.

% =====================================================================
\section{Methods}\label{sec:methods}
% =====================================================================

\subsection{Two-phase plateau-following cycle (V4)}
Plateau detection is a host-side decision loop, so the PC script drives the
firmware step by step. The cycle measures \textbf{tank first, then ref}, so the
5\,L reference is co-aerated throughout the tank phase and converges quickly
when its turn comes:
\begin{enumerate}[nosep,leftmargin=1.6em]
\item \emph{Prep:} \texttt{m3b} (drain KCl from chamber)
$\rightarrow$ \texttt{m1f} (aquarium $\to$ holding)
$\rightarrow$ \texttt{m2f} (holding $\to$ chamber).
\item \emph{Phase A:} \texttt{ron}; measure \texttt{tank} every 30\,s until
plateau (chamber tank + 5\,L aerated together).
\item \emph{Transition:} \texttt{m2b} parks the tank aliquot back in holding;
\texttt{m4f} brings reference into the chamber.
\item \emph{Phase B:} \texttt{ron}; measure \texttt{ref} until plateau
(fast---already near equilibrium).
\item \texttt{calkh}; then cleanup: \texttt{m4b} (recover ref to 5\,L),
\texttt{m1b} (return parked tank to aquarium), \texttt{m3f} (restore KCl soak),
\texttt{airoff} (probe rests in KCl).
\end{enumerate}

\subsection{Two-gate plateau criterion}
Readings are held as integer milli-pH (mpH) to avoid floating-point boundary
jitter. A plateau is declared only when \emph{both} gates hold over a sliding
window (Table~\ref{tab:plateau}): a short \emph{span} gate (last 4 readings,
$\mathrm{max}-\mathrm{min}\le 2$\,mpH) rejects noise, and a longer \emph{net}
gate (last 8 readings, $|w_{-1}-w_{0}|\le 1$\,mpH) rejects a slow monotonic
exponential tail that the span gate alone would mistake for convergence. The
longer net look-back (8 vs.\ 4 points; ``B1'') was the fix for early latches in
which the tank stopped climbing prematurely. Per-phase wall-clock and
read-count caps ($\mathtt{PHASE\_MAX}=7200\,\mathrm{s}$,
$\mathtt{MEAS\_MAX}=240$) and a consecutive-failure cap
($\mathtt{FAIL\_MAX}=5$) bound the loop so it can never hang.

\begin{table}[t]
\centering
\caption{Plateau-following parameters (\texttt{measure\_until\_flat}).}
\label{tab:plateau}
\footnotesize
\begin{tabular}{@{}llp{0.5\linewidth}@{}}
\toprule
Constant & Value & Meaning \\
\midrule
\texttt{FLAT\_SPAN\_N}  & 4 & span window (jitter gate) \\
\texttt{FLAT\_SPAN\_MPH}& 2 & last 4: $\max-\min\le 2$\,mpH \\
\texttt{FLAT\_NET\_N}   & 8 & net look-back (drift gate; B1) \\
\texttt{FLAT\_NET\_MPH} & 1 & last 8: $|w_{-1}-w_0|\le 1$\,mpH \\
\texttt{MEAS\_INTERVAL} & 30\,s & between readings (aeration continuous) \\
\texttt{PHASE\_MAX\_SECS}& 7200\,s & per-phase cap (2\,h; 4\,h total) \\
\texttt{MEAS\_MAX}      & 240 & per-phase read cap \\
\texttt{FAIL\_MAX}      & 5 & consecutive parse failures tolerated \\
\bottomrule
\end{tabular}
\end{table}

Figure~\ref{fig:plateau} shows a measured pair of approach curves. The tank,
freshly drawn into the chamber, climbs a slow first-order tail toward its
ceiling and is held by the net gate until it is genuinely flat (latching at
$\sim$624\,s when the 8-point net drift falls to 1\,mpH). The reference, having
co-aerated in the 5\,L reservoir throughout the tank phase, is already at
equilibrium and latches in $\sim$2.6\,min---a direct illustration of why
measuring tank-first is faster, and of why the span gate alone (satisfied near
$\sim$546\,s) would have latched the tank early.

\begin{figure}[t]
\centering
\begin{tikzpicture}
\begin{axis}[
  width=0.86\linewidth, height=6.2cm,
  xlabel={Elapsed time (s)}, ylabel={pH (equilibrium approach)},
  xmin=-20,xmax=660, ymin=7.825, ymax=7.915,
  grid=both, major grid style={gray!18}, minor grid style={gray!8},
  legend style={at={(0.63,0.55)},anchor=center, fill=white, fill opacity=0.85,
    text opacity=1, draw=gray!40, font=\footnotesize}, legend cell align=left,
  tick label style={font=\footnotesize}, label style={font=\small},
]
\addplot[blue!70!black, mark=*, mark size=1.1pt, thick] coordinates {
(0,7.829)(38,7.832)(77,7.834)(116,7.836)(156,7.838)(195,7.840)(234,7.841)
(273,7.843)(312,7.844)(351,7.845)(390,7.846)(429,7.847)(468,7.848)(507,7.849)
(546,7.849)(585,7.850)(624,7.850)};
\addlegendentry{tank (chamber sample)}
\addplot[red!75!black, mark=square*, mark size=1.1pt, thick, dashed] coordinates {
(0,7.906)(38,7.909)(77,7.909)(117,7.909)(156,7.909)};
\addlegendentry{ref (co-aerated 5\,L)}
\node[anchor=west,font=\scriptsize,blue!50!black] at (axis cs:430,7.843) {net-gate latch @624\,s};
\draw[blue!50!black,->,>=stealth] (axis cs:560,7.844) -- (axis cs:620,7.849);
\end{axis}
\end{tikzpicture}
\caption{Measured plateau-following curves (sealed, net-gate run). The tank
sample (solid) climbs a slow exponential tail and is latched only when the
two-gate criterion (last-4 span $\le 2$\,mpH \emph{and} last-8 net $\le 1$\,mpH)
is met; the co-aerated reference (dashed) is already near equilibrium and latches
quickly. The two series sit at different pH because the underlying samples differ
(this run predates the null campaign); only their respective \emph{plateau}
values enter Eq.~\eqref{eq:dkh}.}
\label{fig:plateau}
\end{figure}

\subsection{Logging and fault handling}
Each completed run appends one line
\texttt{HH ref\_pH tank\_pH 8.448 tank\_kh temp} to \texttt{dkh.dat}. Two
distinct markers encode abnormal outcomes: an \emph{all-zeros} line on hard
failure (timeout, serial loss, or unverified KCl soak), which additionally
\emph{latches}---a subsequent run refuses to measure and re-writes the marker
until a human clears it, protecting the probe from unattended pump cycling; and
a \emph{negative} \texttt{tank\_kh} (magnitude preserved, sign flipped) when a
phase hits its cap without reaching plateau, which the data server reads as
``did-not-plateau'' but which does \emph{not} trip the latch. A \texttt{finally}
block runs an emergency cleanup (air off, drain chamber, restore KCl soak) on
any non-completion.

\subsection{Null-test protocol}
The diagnostic backbone is the \emph{null test}: the reference and tank vessels
are filled with the \emph{same} water so the true alkalinity difference is zero
and the correct output is exactly $\dpH=0$, $\mathrm{dKH}=8.448$. Two variants
are used. In a \emph{partial null}, only the small tank aliquot is replaced with
fresh seawater while the aged 5\,L reference is retained, so a change in \dpH{}
isolates the tank water's contribution. In a \emph{complete null}, reference
water is also placed in the tank chamber, so the water difference is zero
\emph{by construction} and any residual \dpH{} is purely instrumental.

\subsection{Revision history and the one-change-at-a-time rule}
The build evolved through five revisions (Table~\ref{tab:versions}). Changes
were made one causal axis at a time, so that each measurement campaign tests a
single mechanism; where two constants were changed together
(e.g.\ stabilization window and convergence band), they were justified as the
\emph{same} causal axis (response completeness), not two independent variables.

\begin{table}[t]
\centering
\caption{Method/firmware revisions. ``ron held'' = continuous aeration between runs.}
\label{tab:versions}
\footnotesize
\begin{tabular}{@{}llp{0.56\linewidth}@{}}
\toprule
Rev & Period & Change vs.\ prior \\
\midrule
V0 & 6/14--6/15 & First symmetric build; reference drawn from 5\,L into a cup; fixed 1200\,s aeration. \\
V1 & 6/15--6/16 & Added continuous aeration between runs (\texttt{ron} held). \\
V2 & 6/16--6/17 & Reference taken as a small directly-aerated aliquot (holding $\to$ chamber); aeration off during the reading. \\
V3 & 6/17 & Aeration \emph{during} measurement (pin tank/ref to same \pco{}); path symmetrized; KCl-rinse bubble clean (later dropped). \\
V4 & 6/17$\to$ & \textbf{Plateau-following} to true equilibrium (no fixed time); two-phase tank-then-ref; anti-hang caps; emergency cleanup. Subsequently: \emph{sealed common headspace}, \emph{5\,L active anchor}, and the two-gate (B1) criterion. \\
\bottomrule
\end{tabular}
\end{table}

% =====================================================================
\section{Results}\label{sec:results}
% =====================================================================
Table~\ref{tab:data} lists the full campaign. Throughout, $\dpH<0$ means the
tank read more acidic than the reference (lower apparent alkalinity), and by
Eq.~\eqref{eq:dkh} the raw error is
$\mathrm{dKH}-8.448 = 8.448\,(10^{\dpH}-1)$.

{\scriptsize\setlength{\tabcolsep}{4pt}
\begin{longtable}{@{}r l l r r r r r p{0.30\linewidth}@{}}
\caption{Complete measurement campaign (30 runs). ``abs pH'' is the common-mode
level (a room-\co{} proxy within a single day only). Config abbreviations:
S = sealed headspace, A = 5\,L active anchor, N = net-gate, B1 = net look-back 8.
\textbf{Null staging:} a fresh seawater batch is aliquoted at the start; PN =
partial null (the $100\,\mathrm{mL}$ tank chamber alone is refilled with that
fresh aliquot while the aged $5\,\mathrm{L}$ reference is kept, isolating the
tank-water contribution); CN = complete null (reference water is then transferred
into the tank chamber as well, so both vessels hold \emph{identical} water and the
water difference is zero by construction).}
\label{tab:data}\\
\toprule
\# & Date/time & Cfg & pH$_\mathrm{ref}$ & pH$_\mathrm{tank}$ & \dpH{} & dKH & $T$ & Conditions \\
\midrule
\endfirsthead
\multicolumn{9}{l}{\scriptsize\emph{Table~\ref{tab:data} (continued)}}\\
\toprule
\# & Date/time & Cfg & pH$_\mathrm{ref}$ & pH$_\mathrm{tank}$ & \dpH{} & dKH & $T$ & Conditions \\
\midrule
\endhead
\midrule
\multicolumn{9}{r}{\scriptsize\emph{continued on next page}}\\
\endfoot
\bottomrule
\endlastfoot
1 & 06-14 20:12 & V0 & 7.959 & 8.021 & $+0.062$ & 9.741 & 26.7 & first manual symmetric run \\
2 & 06-14 21:00 & V0 & 7.997 & 8.072 & $+0.075$ & 10.054& 26.2 & --- \\
3 & 06-15 05:00 & V0 & 8.057 & 8.077 & $+0.020$ & 8.843 & 26.4 & dawn but $+$; window open (ventilated), low \co{} \\
4 & 06-15 13:00 & V1 & 8.050 & 8.042 & $-0.008$ & 8.293 & 27.0 & first continuous aeration \\
5 & 06-15 21:00 & V1 & 8.109 & 8.091 & $-0.018$ & 8.109 & 27.3 & clean low-\co{} point \\
6 & 06-16 05:00 & V1 & 7.810 & 7.751 & $-0.059$ & 7.362 & 27.5 & dawn closed-room \co{} spike (both abs pH fell $\sim$0.3) \\
7 & 06-16 13:00 & V1b& 8.091 & 8.063 & $-0.028$ & 7.922 & 27.7 & tighter window/band \\
-- & 06-16 21:00 & --- & \multicolumn{5}{c}{\emph{failed (0.000; power cut, port semaphore)}} & \\
8 & 06-16 21:21 & V2 & 8.042 & 8.021 & $-0.021$ & 8.039 & 28.6 & first V2 (manual) \\
9 & 06-17 05:00 & V2 & 7.997 & 7.939 & $-0.058$ & 7.386 & 27.8 & V2 dawn test \emph{failed}; regressed to V1 \\
10& 06-17 13:00 & V3 & 8.109 & 8.091 & $-0.018$ & 8.095 & 28.2 & first V3; ref under-equilibrated (5 reads) \\
11& 06-17 21:00 & V4 & 8.113 & 8.071 & $-0.042$ & 7.669 & 27.8 & first V4 + trim-mean firmware; clean plateaus \\
12& 06-18 05:00 & V4 & 7.738 & 7.695 & $-0.043$ & 7.657 & 28.2 & \textbf{decisive:} dawn $-0.043\approx$ evening $-0.042$ despite 0.4 abs-pH swing $\Rightarrow$ \co{}-level independence \\
13& 06-18 13:00 & V4 & 8.081 & 8.055 & $-0.026$ & 7.950 & 28.3 & same low \co{} as \#11 yet $-0.026$; dKH $+0.29$ jump $\Rightarrow$ baseline \emph{not} constant (evaporation, open 200\,mL day 5) \\
14& 06-19 05:00 & V4+S & 7.976 & 7.968 & $-0.008$ & 8.283 & 28.1 & \textbf{seal verif.\,\textcircled{1}}: dawn dip collapses $-0.05\!\to\!-0.008$; plateau 33$\to$4 reads \\
15& 06-19 13:00 & V4+S & 7.957 & 7.947 & $-0.010$ & 8.255 & 28.6 & \textbf{seal verif.\,\textcircled{2}}: dawn$\to$noon jump $+0.29\!\to\!-0.03$ ($\sim$10$\times$); evaporation removed \\
16& 06-19 21:00 & V4+S & 7.969 & 7.968 & $-0.001$ & 8.421 & 26.8 & near-perfect null (raw err $-0.027$, smallest); but $+0.166$ vs.\ \#14/15 $\Rightarrow$ offset not a perfect constant; AC transient ($-1.8$\,\textcelsius) \\
17& 06-20 05:00 & V4+S & 7.922 & 7.871 & $-0.051$ & 7.521 & 27.7 & dawn dip recurs; tank 11$\times$ monotone = early latch (not true plateau); AC cooling slowed kinetics \\
18& 06-20 15:00 & V4+SAN& 7.975 & 7.929 & $-0.046$ & 7.602 & 27.1 & first 5\,L anchor; tank \emph{true} plateau (34$\times$, 21.6\,min) yet $-0.046$ $\Rightarrow$ \textbf{genuine gap}, not latch artifact \\
19& 06-20 18:11 & V4+S,2$\times$& 7.979 & 7.924 & $-0.055$ & 7.443 & 26.4 & controlled exp; 2$\times$ aeration halves climb (1296$\to$711\,s) but \dpH{} unchanged $\Rightarrow$ \emph{not} kinetics \\
20& 06-20 18:57 & V4+S,2$\times$& 7.975 & 7.931 & $-0.044$ & 7.636 & 26.7 & ref-first + hose swap; gap persists $\Rightarrow$ order/path/non-equilibrium all rejected \\
21& 06-20 19:50 & V4+S & 7.975 & 7.926 & $-0.049$ & 7.539 & 26.9 & reproduction \\
22& 06-20 20:29 & V4+SA& 7.977 & 7.921 & $-0.056$ & 7.426 & 26.9 & tank-first+park; ref fastest ever (4$\times$); tank early latch (7.921) $\Rightarrow$ motivates B1 \\
23& 06-20 21:00 & V4+SA,B1& 7.979 & 7.926 & $-0.053$ & 7.474 & 27.0 & \textbf{B1 ok}: tank 25$\times$/945\,s true plateau; confirms \#22 was $\sim$5\,mpH short; gap (7th) \\
24& 06-21 05:00 & V4+SA,B1& 7.974 & 7.928 & $-0.046$ & 7.594 & 26.7 & dawn matches evening cluster $\Rightarrow$ time-of-day dependence ruled out (gap, 8th) \\
25& 06-21 06:00 & V4+S,PN& 7.973 & 7.963 & $-0.010$ & $-8.255$ & 26.7 & \textbf{partial null}: fresh tank only; tank pH $+37$\,mpH, \dpH{} $-0.05\!\to\!-0.010$; tank not plateaued (old cap) $\Rightarrow$ lower bound \\
26& 06-21 13:00 & V4+S,PN& 7.964 & 7.956 & $-0.008$ & 8.298 & 27.2 & \textbf{partial null, full eq.}: dKH 8.298, raw err $-0.15$; back in good cluster; 4\,h cap validated \\
27& 06-21 19:00 & V4+S,CN& 7.960 & 7.957 & $-0.003$ & 8.387 & 27.4 & \textbf{complete null}: reference water into tank chamber too $\Rightarrow$ both identical; raw err $-0.061$ = pure instrument offset; $100\,$mL vs.\ 5\,L cancels \\
28& 06-21 21:00 & V4+S,CN& 7.959 & 7.958 & $-0.001$ & 8.434 & 27.4 & \textbf{complete null} (2nd): $\dpH-0.001$ (resolution limit), raw err $-0.014$ (smallest); reconfirms the $\le0.06\dkh$ offset \\
-- & 06-22 05:00 & V4+S,CN & \multicolumn{5}{c}{\emph{failed (cap)}} & 55-min scheduler cap killed it mid-ref; tank had plateaued (7.955); fix: 5\,h cap \\
29& 06-22 09:00 & V4+S,CN& 7.959 & 7.948 & $-0.011$ & 8.226 & 27.4 & \textbf{aged complete null} ($\sim$14\,h, $100\,\mathrm{mL}$ exposed aliquot): null decayed to raw err $-0.22$; tank true plateau 59$\times$ (long aeration drives precipitation, KH$\downarrow$) \\
30& 06-22 13:00 & V4+S,CN& 7.950 & 7.961 & $+0.011$ & 8.664 & 27.6 & \textbf{aged null reverses} ($\sim$18\,h): short plateau (tank 8$\times$), $\dpH>0$, dKH $8.664$ (raw err $+0.22$) $\Rightarrow$ evaporative concentration (KH$\uparrow$) overtakes precipitation \\
\bottomrule
\end{longtable}
}

\subsection{The dawn-\co{} error and its diagnosis}
The earliest clear pathology was a dawn collapse of \dpH{} (run \#6,
$-0.059$; error $-1.09\dkh$). The decisive clue was common mode: \emph{both}
absolute pH values fell $\sim0.3$ overnight (ref $8.109\!\to\!7.810$, tank
$8.091\!\to\!7.751$), reversing the daytime upward trend---the signature of a
closed-room \co{} build-up acidifying the aeration water. A natural experiment
confirmed it: on the one ventilated night (run \#3, window open) the absolute
pH stayed high and \dpH{} was a normal $+0.020$, whereas closed nights gave
$-0.058/-0.059$. Crucially, room \co{} is exactly the common-mode variable the
differential is \emph{supposed} to cancel; its leakage into \dpH{} signalled a
broken ref/tank symmetry, not an environmental problem to be ventilated away.

\subsection{Plateau-following and the inter-phase drift conflict}
Measuring to a true plateau (V4) removed the \co{}-\emph{level} dependence: runs
\#11/\#12 gave $\dpH=-0.042$ and $-0.043$ across a 0.4-unit swing in absolute
pH. But the first V4 run had exposed a competing failure: a 31-minute tank
measurement whose pH rose to a peak then \emph{fell} (room \co{} drifting during
the measurement), latching at a value set by whenever the single probe happened
to sample each vessel. This \emph{inter-phase drift}, of order
\begin{equation}
\epsilon_\mathrm{drift} \;\approx\; \Delta t_{\mathrm{tank{-}ref}}\times \frac{dC}{dt},
\label{eq:drift}
\end{equation}
sets up a fundamental conflict with a single probe: full equilibrium needs long
measurements, but long measurements widen the tank--ref sampling gap
$\Delta t$ and thus the drift. The same form with $dT/dt$ explains run \#16,
where an air-conditioner cooling overshoot ($-1.8$\,\textcelsius{} during the
run) coincided with a $+0.166\dkh$ excursion.

\subsection{Sealing collapses both confounds}
A single \emph{sealed common headspace} resolves the conflict at the source. By
compelling the reference and tank to share a single common air volume, it makes
the common \pco{} intrinsic rather than coincidental, blocks room-\co{}
excursions, and additionally suppresses the evaporation that had been
concentrating the open tank aliquot.
The effect was immediate (runs \#14/\#15): the dawn dip collapsed from
$-0.05$ to $-0.008$; the dawn$\to$noon dKH jump shrank $\sim$10$\times$
(from $+0.29$ open to $-0.03$ sealed); and the plateau time was reduced from
$\sim$33 readings ($\sim$50\,min) to $\sim$4 ($\sim$5\,min)---which in turn
collapses $\Delta t$ in Eq.~\eqref{eq:drift}, structurally removing the
inter-phase drift. The uncorrected error fell from $-0.78$ to $\sim-0.18\dkh$.

\subsection{The active anchor and the persistence of a genuine gap}
Sealing alone left a slow headspace drift, because a passive shared air volume
re-equilibrates only by surface diffusion (tens of minutes). Placing an air
stone \emph{in} the 5\,L reference (the ``anchor'') actively pins the shared
\pco{} within minutes; a volume audit confirms the dominance hierarchy
(sample $\sim$3\,\si{\micro mol} $\ll$ headspace $\sim$65\,\si{\micro mol}
$\ll$ 5\,L $\sim$500\,\si{\micro mol}). Yet with the anchor and the net-gate
in place, a $\sim$$-0.046$ to $-0.053$ gap \emph{persisted} even when the tank
reached a verified true plateau (run \#18: 34 readings, 21.6\,min). A
controlled pair of experiments (runs \#19/\#20) then rejected, in turn, four
device-side explanations: doubling the aeration halved the climb time but left
\dpH{} unchanged (\emph{not} kinetics); reversing the measurement order and
swapping hoses did not reverse the sign (\emph{not} order, warm-up, or fluid
path); and a tank started from a higher initial pH settled to the \emph{same}
equilibrium (\emph{not} under-equilibration). The gap was a property of the
\emph{water}.

\subsection{Null experiments localize the error}
Because the device hypotheses were exhausted, we tested the water directly.
A \emph{partial null} (run \#25, fresh seawater in the tank chamber only)
collapsed \dpH{} from $-0.05$ to $-0.010$ (tank pH $+37$\,mpH); at full
equilibrium (run \#26) it gave $\mathrm{dKH}=8.298$, raw error $-0.15$---back in
the good cluster. Swapping fresh water into the tank had recovered almost the
entire error, implicating the aged tank aliquot. The \emph{complete null}
(run \#27), with reference water in \emph{both} vessels so the water difference
is zero by construction, returned $\dpH=-0.003$, $\mathrm{dKH}=8.387$, raw error
$\mathbf{-0.061}$, with both sides at verified true plateaus despite the
$100\,\mathrm{mL}$:$5\,\mathrm{L}$ volume mismatch---a direct confirmation of
volume independence (Sec.~\ref{sec:principle}).

\subsection{Error decomposition and accuracy}
The two nulls decompose the headline error (Table~\ref{tab:budget},
Fig.~\ref{fig:budget}):
\begin{equation}
\underbrace{-0.92\dkh}_{\text{raw}} \;=\;
\underbrace{-0.86\dkh}_{\substack{\text{aged-tank alkalinity loss}\\(\ce{CaCO3}\text{ precip./biofilm})}}
\;+\;
\underbrace{-0.06\dkh}_{\substack{\text{instrument offset}\\(\dpH=-3\,\mathrm{mpH})}}.
\end{equation}
Across the seven-point cluster (runs \#18--24) the \emph{precision} was
$\dpH = -0.0499\pm0.0048$ ($\approx$5\,mpH), $\mathrm{dKH}=7.531\pm0.084$---a
scatter about one-third of the $\pm0.25\dkh$ goal. With the bulk error
identified as a sample artifact and the instrument offset at $-0.06\dkh$
(one-quarter of the goal), the monitor meets $\pm0.25\dkh$ \emph{uncorrected};
zero-point calibration was judged unnecessary, and with normal (non-degraded)
reef water the uncorrected error should fall within $\pm0.1\dkh$.

\begin{table}[t]
\centering
\caption{Error budget after full diagnosis.}
\label{tab:budget}
\footnotesize
\begin{tabular}{@{}lcl@{}}
\toprule
Component & Magnitude & Character / remedy \\
\midrule
Aged-tank alkalinity loss & $-0.86\dkh$ & sample handling; use fresh aliquot \\
Instrument offset & $-0.06\dkh$ & $\dpH=-3$\,mpH; below correction value \\
Precision (1$\sigma$) & $\pm0.08\dkh$ & electrode noise + residual drift \\
Room-\co{} dependence & $\approx 0$ & removed by sealing \\
Evaporation confound & $\approx 0$ & removed by sealing \\
\bottomrule
\end{tabular}
\end{table}

\begin{figure}[t]
\centering
\begin{tikzpicture}
\begin{axis}[
  ybar, bar width=30pt,
  width=0.82\linewidth, height=5.8cm,
  symbolic x coords={Raw,Degrade,Offset},
  xtick=data,
  xticklabels={Raw error,Aged-tank degrade,Instrument offset},
  nodes near coords, nodes near coords align={below},
  every node near coord/.append style={font=\footnotesize,
    /pgf/number format/.cd, fixed, fixed zerofill, precision=2},
  ymin=-1.05, ymax=0.12,
  ylabel={Contribution to error (dKH)},
  tick label style={font=\footnotesize}, label style={font=\small},
  ymajorgrids, major grid style={gray!18},
  enlarge x limits=0.28,
]
\addplot[draw=black, fill=blue!22] coordinates {(Raw,-0.92)(Degrade,-0.86)(Offset,-0.06)};
\draw[gray] (axis cs:Raw,0) -- (axis cs:Offset,0);
\end{axis}
\end{tikzpicture}
\caption{Decomposition of the $-0.92\dkh$ raw error. The complete null isolates
the instrument offset at $-0.06\dkh$ (one-quarter of the $\pm0.25\dkh$ goal); the
partial null attributes the remaining $-0.86\dkh$ to alkalinity loss in the aged
tank aliquot (\ce{CaCO3} precipitation / biofilm)---a sample artifact, not an
instrument fault.}
\label{fig:budget}
\end{figure}

\subsection{Time-resolved breakdown of the null}
The decomposition makes a falsifiable prediction: if the bulk error is sample
chemistry rather than electronics, an otherwise-perfect null should \emph{drift}
as the sample ages, in whichever direction the dominant chemistry dictates. We
tested this by re-running the complete null on the same $100\,\mathrm{mL}$
aliquot over the following day, without touching the instrument
(Fig.~\ref{fig:degrade}, runs \#29--30). The raw error---$-0.061$ and
$-0.014\dkh$ at 0 and 2\,h---first fell to $-0.222\dkh$ at $\sim$14\,h, then
\emph{reversed} to $+0.216\dkh$ at $\sim$18\,h; both extremes were reached at
verified true plateaus (tank 59 and 8 readings), so each is genuine, not a
latching artifact. They are opposite signs of one vulnerability: a long aeration
run (\#29) raises carbonate saturation and drives \ce{CaCO3} precipitation,
lowering alkalinity (KH$\downarrow$), whereas a short run after prolonged
exposure of the small, repeatedly opened aliquot (\#30) lets evaporative
concentration win (KH$\uparrow$). Either way the small exposed aliquot wanders by
$\sim\pm0.2\dkh$ while the instrument offset floor stays at its fresh value. This
is the time-domain confirmation of the error decomposition---and a practical
caveat: a small, aged, exposed aliquot is unreliable in \emph{both} directions,
so the sample must be fresh and adequately sized.

\begin{figure}[t]
\centering
\begin{tikzpicture}
\begin{axis}[
  width=0.84\linewidth, height=6.0cm,
  xlabel={Time since first complete null (h)},
  ylabel={Raw null error (dKH)},
  xmin=-1, xmax=19.5, ymin=-0.33, ymax=0.33,
  grid=both, major grid style={gray!18},
  tick label style={font=\footnotesize}, label style={font=\small},
]
\draw[gray,thick] (axis cs:-1,0) -- (axis cs:19.5,0);
\draw[green!45!black,dashed] (axis cs:-1,0.25) -- (axis cs:19.5,0.25);
\draw[green!45!black,dashed] (axis cs:-1,-0.25) -- (axis cs:19.5,-0.25);
\node[anchor=east,font=\scriptsize,green!40!black] at (axis cs:19.4,0.29) {$\pm0.25\dkh$ goal};
\addplot[blue!70!black, mark=*, thick,
  error bars/.cd, y dir=both, y explicit]
  coordinates {
  (0,-0.061) +- (0,0.08)
  (2,-0.014) +- (0,0.08)
  (14,-0.222) +- (0,0.08)
  (18,0.216) +- (0,0.08)
  };
\node[font=\scriptsize,blue!45!black,align=center] at (axis cs:10.6,-0.135) {precipitation\\KH$\downarrow$};
\node[font=\scriptsize,blue!45!black,align=center] at (axis cs:15.2,0.125) {evaporation\\KH$\uparrow$};
\end{axis}
\end{tikzpicture}
\caption{Time-resolved \emph{bidirectional} drift of the complete null. With
reference water in \emph{both} vessels (water difference zero by construction),
the raw error stays within the $\pm0.08\dkh$ precision (error bars) and the
$\pm0.25\dkh$ goal for the first hours, then wanders as the small
($100\,\mathrm{mL}$), exposed tank aliquot ages: a long aeration run drives
\ce{CaCO3} precipitation (KH$\downarrow$, $-0.22\dkh$ at $\sim$14\,h), while
prolonged exposure lets evaporative concentration win (KH$\uparrow$, $+0.22\dkh$
at $\sim$18\,h). The electronics are unchanged; only the sample alkalinity
drifts, in either direction---confirming that the dominant error term is sample
chemistry (cf.\ Fig.~\ref{fig:budget}).}
\label{fig:degrade}
\end{figure}

% =====================================================================
\section{Discussion}
% =====================================================================
\paragraph{Implications of the error decomposition.} The natural response to a
stable $\sim-0.8\dkh$ offset is to zero-point calibrate. Resisting that---on the
methodological principle that a calibration constant should be applied only
after independent replication, and never to a small non-independent
sample---was decisive, because the offset turned out \emph{not} to be a
constant device property (it varied $\pm0.085\dkh$ across the sealed cluster and
ultimately proved to be mostly degraded sample water). Calibrating it away would
have embedded a sample artifact in the instrument's calibration and masked the
genuine $-0.06\dkh$ floor.

\paragraph{External validation.} Our independently derived error structure
mirrors published behaviour of the commercial AquaWiz, lending it external
support. Community reports identify room-\co{} variation as the dominant error
and a sealed container as the field fix; the manufacturer's own guidance---that
a sharp \co{} change ``only affects readings for about an hour'' and that one
should ``connect the air intake to the skimmer's outdoor air line''---matches
both our $\sim$1-hour inter-phase drift episode and our gas-reference-fixing
remedy (we realize it by sealing rather than by an outdoor line). The
second-most-reported commercial error, bubble-quality degradation from salt
creep ($>2\dkh$ error, clean every six months), matches our aeration-sufficiency
analysis. Reported field accuracy ($\le0.2\dkh$ vs.\ a Hanna checker;
$\le0.75\dkh$ uncalibrated over seven weeks; ``under $0.5\dkh$ = excellent, use
for trend'') brackets our $\pm0.25\dkh$ result and our trend-oriented intent.
Notably, commercial units are managed by periodic calibration and cleaning and do not pursue a
true equilibrium plateau; our plateau-following step extends this further.

\paragraph{Scientific grounding.} The kinetic separation underlying the method
is well established: the aqueous \co{} hydration/dehydration relaxation completes
in $\sim$16\,s \cite{johnson1982}, so chemistry is never rate-limiting;
the slow step is physical gas exchange, $\sim$15\,min for direct
bubbling \cite{takahashi}, consistent with our observed plateau times. The
differential ``$\at{}$ from \pco{}-equilibration plus pH'' principle has a recent
analytical-chemistry basis demonstrated down to $0.5\,\mathrm{mL}$ samples at
$\pm1$--$2\,\si{\micro mol\,kg^{-1}}$ precision \cite{fleger2025}, supporting
small-volume miniaturization as the correct direction.

\paragraph{Limitations.} (i) With a single probe the inter-phase drift of
Eq.~\eqref{eq:drift} cannot be driven to zero; it is only suppressed (by sealing
and by minimizing $\Delta t$). (ii) The dominant historical error was sample
degradation, so the operating discipline---use a fresh, adequately sized tank
aliquot and recirculate rather than store---is part of the instrument, not an
afterthought. (iii) Long plateaus under slow drift can make a measurement run to
hours; the wall-clock caps bound this but a hard external scheduler limit must be
set above the code's 4-hour ceiling. (iv) Absolute pH is informative only as a
within-day \co{} proxy; only \dpH{} is quantitative.

\paragraph{Recommended operation.} Seal the common headspace; anchor the
reference with active aeration; measure tank-then-ref with the two-gate plateau
criterion; use fresh sample water; clean the air path periodically; and treat
the output as a trend instrument calibrated, if at all, against an independent
kit on a monthly cadence keyed to the ref$\leftrightarrow$tank divergence.

% =====================================================================
\section{Conclusion}
% =====================================================================
A reagent-free, single-probe differential-pH aeration monitor can measure reef
carbonate alkalinity to better than $\pm0.25\dkh$ \emph{without} zero-point
calibration, once three design rules are observed: a single sealed common
headspace, plateau-following to true gas equilibrium, and an actively aerated
reference anchor. The value of the eight-day campaign was less in any one number
than in \emph{decomposing} a $-0.92\dkh$ raw error: null experiments showed that
$-0.86\dkh$ of it was alkalinity loss in a degraded sample aliquot and only
$-0.06\dkh$ was the instrument. The differential design delivered its promised
common-mode rejection of room \co{} and probe drift; what remained was chemistry
in a beaker, not error in the electronics. We expect the design rules and the
null-decomposition methodology to transfer to other low-cost alkalinity
instruments.

% ---------------------------------------------------------------
\section*{Reproducibility}
Firmware, the host measurement script (\texttt{measure\_kh\_once.py}), the raw
log (\texttt{dkh.dat}), and the full measurement ledger are available in the
project repository~\cite{repo}.

\section*{Acknowledgments}
This project was completed thanks to the passion of Mango-miyeok of REEF FAMILY
and all the participants of the DIY meetup.

% ---------------------------------------------------------------
\begin{thebibliography}{9}
\bibitem{repo} nowforyou (REEF FAMILY), ``ReefWiz: open differential-pH
aeration alkalinity monitor (firmware, host scripts, measurement ledger),''
project repository, \url{https://github.com/taeseokyi/reefwiz}.
\bibitem{johnson1982} K.~S.~Johnson, ``Carbon dioxide hydration and dehydration
kinetics in seawater,'' \emph{Limnol.\ Oceanogr.} \textbf{27}(5), 849--855
(1982). doi:10.4319/lo.1982.27.5.0849.
\bibitem{soli} A.~L.~Soli and R.~H.~Byrne, ``CO\textsubscript{2} system
hydration and dehydration kinetics and the equilibrium CO\textsubscript{2}/H\textsubscript{2}CO\textsubscript{3}
ratio in aqueous NaCl solution,'' \emph{Mar.\ Chem.} (2002).
\bibitem{zeebe2001} R.~E.~Zeebe and D.~Wolf-Gladrow, \emph{CO\textsubscript{2}
in Seawater: Equilibrium, Kinetics, Isotopes}, Elsevier Oceanography Series 65
(2001).
\bibitem{takahashi} T.~Takahashi, ``Methods for measurement of
$p\mathrm{CO_2}$ and total CO\textsubscript{2} in seawater'' (carbonate-system
methodology; direct-bubbling equilibration $\sim$15\,min).
\bibitem{fleger2025} K.~Fleger, X.~Liu, W.~Berelson, J.~Adkins \emph{et al.},
``Total alkalinity measurements in small samples based on
CO\textsubscript{2} equilibration and spectrophotometric pH,''
\emph{Anal.\ Chim.\ Acta} (2025). doi:10.1016/j.aca.2025.344432.
\bibitem{roberts2005} (Gas-stripping first-order equilibration;
$\ln(C_0/C_t)\propto \phi/V$.) Roberts, \emph{Geophys.\ Res.\ Lett.} (2005).
\bibitem{egleston2010} C.~S.~Egleston, C.~L.~Sabine, F.~M.~M.~Morel,
``Revelle (buffer) factor of the seawater carbonate system,''
\emph{Global Biogeochem.\ Cycles} (2010).
\bibitem{community} Reef-hobbyist community field reports on the commercial
AquaWiz alkalinity monitor (room-\co{} error, sealed-container fix, bubble
degradation, manufacturer guidance): Reef2Reef threads \#1159272, \#1073924,
\#1115439; UltimateReef \#939234; Bay Area Reefers \#40433.
\end{thebibliography}

\end{document}

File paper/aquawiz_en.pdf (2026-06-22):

## A Low-Cost Single-Probe Differential-pH Aeration Monitor for Seawater Carbonate Alkalinity: Systematic-Error Decomposition and Sub-0.25 dKH Accuracy via Sealed Common-Headspace Equilibration

nowforyou∗1

1REEF FAMILY

June 22, 2026

Abstract

Carbonate alkalinity (“KH”, expressed in degrees, dKH) is the single most control-critical waterchemistry parameter in reef aquaria, yet affordable continuous monitors are scarce and reagent titration is laborious. We describe an open, reagent-free monitor that infers alkalinity from the equilibrium pH a seawater sample reaches after aeration to atmospheric CO2, using a single pH probe to measure an aquarium sample (“tank”) and a known-alkalinity reference (“ref”) in immediate succession. Because dKH is computed from the pH difference (KHtank = KHref ·10∆pH), absolute probe drift and room-CO2 excursions are common-mode signals that cancel. Over a nine-day instrumented campaign (29 logged measurements across five firmware/method revisions) we observed a persistent uncorrected error of −0.92 dKH and, rather than zero-point calibrating it away, decomposed it. Three interventions—(i) plateau-following measurement to true gas equilibrium, (ii) a single sealed common headspace shared by sample, reference and pump intake, and (iii) an actively aerated 5 L reference anchor that pins the headspace pCO2— collapsed the dawn-CO2 error and the diurnal evaporation confound, and shrank measurement scatter to SD = ±0.08 dKH (about one-third of the ±0.25 dKH design goal). A sequence of null experiments (identical water in both vessels, true ∆pH = 0) then localized the residual: a complete null returned ∆pH = −0.003, dKH = 8.387, i.e. an instrument offset of only −0.06 dKH. The remaining −0.86 dKH was traced to alkalinity loss (CO2 driven CaCO3 precipitation / biofilm) in the days-old, small, open tank aliquot—a sample-handling artifact, not a measurement fault. A re-run of the null on the same aged aliquot a day later showed the offset decaying from −0.06 to −0.22 dKH with the electronics untouched, confirming the attribution in the time domain. The instrument therefore meets the ±0.25 dKH goal uncorrected, with zero-point calibration deemed unnecessary. Our independently obtained error structure (room-CO2 sensitivity, bubble-quality dependence, sealing as the remedy) reproduces the published behaviour of
a commercial counterpart, providing external validation of both the diagnosis and the remedy.

Keywords: reef aquarium; carbonate alkalinity; total alkalinity; CO2 equilibration; differential pH; low-cost instrumentation; common-mode rejection; CaCO3 precipitation.

∗Correspondence: taeseokyi@gmail.com

### 1 Introduction

Stony corals and other calcifying reef organisms deposit calcium carbonate at a rate that continuously consumes carbonate alkalinity. In a closed reef aquarium the resulting alkalinity drawdown is fast (often 0.5–1.5 dKH day⁻¹
) and swings of more than ∼ 1 dKH are implicated in coral tissue stress. Alkalinity (AT, conventionally reported by hobbyists as “KH” in German degrees, 1 dKH ≈ 0.357 meq L⁻¹
) is therefore the parameter most worth measuring often. The accessible options are unsatisfying for continuous use. Manual reagent titration (e.g. commercial drop kits) is accurate but labour-intensive and discrete. Colorimetric robots automate titration but consume reagent and are expensive. Direct potentiometric pH alone is not an alkalinity measurement, because seawater pH depends jointly on AT and pCO2

, and aquarium pCO2 varies strongly over the day (room ventilation, photosynthesis, respiration).
A reagent-free alternative exploits the fact that if a sample is aerated until its pCO2

equilibrates
with the surrounding air, the equilibrium pH becomes a single-valued function of alkalinity at fixed temperature and salinity. A commercial product (AquaWiz) is built on this principle and is used by reef hobbyists, but community reports document recurring inaccuracy tied to room-CO2 fluctuation and to aeration/bubble quality. The contribution of this paper is not the principle but a quantitative diagnosis: starting from a working DIY build, we conduct a nine-day instrumented campaign, expose a −0.92 dKH raw error, and show by construction (null experiments) that essentially all of it is a sample-handling artifact rather than an instrument limitation—reducing the true instrument offset to −0.06 dKH and meeting a ±0.25 dKH goal without calibration. Along the way we establish a small set of design rules (sealed common headspace; plateau-following to true equilibrium; an actively aerated reference anchor; a two-gate plateau criterion) that we expect to generalize to any single-probe differential-pH alkalinity monitor.

### 2 Measurement Principle

### 2.1 Aeration makes equilibrium pH a proxy for alkalinity

At fixed temperature T and salinity S, the seawater carbonate system has two degrees of freedom; fixing any two of {AT, DIC, pCO2

, pH} determines the rest. Aeration with a large excess of room air drives the dissolved CO2 toward Henry’s-law equilibrium with the gas phase, [CO2]aq = KH pCO2 ,
so that pCO2

(water) → pCO2

(air). Once pCO2
is clamped by the atmosphere, the equilibrium pH is a single-valued function of alkalinity:

pHeq = f(AT, pCO2

, T, S). | (1)

With pCO2

, T, S held common, the only variable that can move pHeq is AT. Measured equilibrium pH is therefore a proxy for alkalinity.

### 2.2 Why the differential cancels room CO2

The instrument never relies on the absolute value of pCO2

. It aerates the reference and the tank sample to the same atmospheric ceiling (in the final design, by aerating both against one shared headspace simultaneously, Sec. 4) and reports the difference of their equilibrium pH. Because the absolute pCO2
term is common to both samples, it cancels in the difference: a room-CO2 excursion is a common-mode signal that drops out. What survives the subtraction is the true alkalinity difference plus electrode noise (±0.005–0.01 pH). This is the central robustness argument of the method, and the reason a single probe (rather than two matched probes) is used: a single sensor’s slow asymmetry-potential and reference-junction drift load identically onto both readings and cancel in ∆pH.

### 2.3 Over-aeration is impossible; only insufficient aeration errs

Equation (1) has a hard ceiling at pCO2

(air): once the water reaches atmospheric equilibrium, further aeration cannot raise pH. There is consequently no “over-aeration” failure mode. Error enters only through insufficiency: if residual CO2 remains in one vessel, that side’s pH is unfairly depressed and a spurious ∆pH appears. The differential’s assumption is precisely that ref and tank share the same pCO2

; broken symmetry breaks the cancellation. This motivates measuring to a genuine plateau rather than for a fixed time (Sec. 4).

### 2.4 Volume independence at full equilibrium

Equation (1) contains no volume term (Henry’s law is intensive). Hence even a large volume mismatch—in our final null, 100 mL of tank water against a 5 L reference—produces zero differential error provided both vessels reach full equilibrium. The familiar “equal volumes for symmetry” rule applies only under partial equilibration, where unequal volumes sit at different points on the first-order approach curve C(t) − C

∗ = (C0 − C

∗
) e

−t/τ . The true requirements are just (a) both fully equilibrated and (b) matched pCO2 and T. The larger volume is rate-limiting, with a time constant

τ ∝

V

KH Qgas

β ∼

1
VVM
β, | (2)

where VVM = Qgas/V is gas volume per liquid volume per minute and β is a seawater chemical factor (only trace [CO2]aq is strippable; the Revelle buffering raises τ by ∼ 8–15×). Equation (2) is the basis for the “increase aeration to shorten the measurement” lever discussed later, and for the choice to miniaturize the rate-limiting reference.

### 2.5 The differential dKH formula

The firmware (Arduino Nano / ATmega328P; pH via DFRobot Gravity probe + ADS1115 16-bit ADC) digitizes one probe, reading reference then tank pH, and computes

KHtank = KHref · 10⁻⁽pHref−pHtank) = KHref · 10∆pH | (3)

with ∆pH ≡ pHtank −pHref and KHref = 8.448 dKH an EEPROM-stored anchor constant (set by a calref command after evaporation top-off; not a per-run measurement—this is why the reference column reads a constant 8.448 in every log line). Equation (3) depends only on ∆pH; absolute pH cancels exactly. Differentiating,

d KHtank
d ∆pH
∆pH=0

= KHref ln 10 ≈ 19.45 dKH pH⁻¹
, | (4)

i.e. 0.01 pH of uncancelled difference maps to ≈ 0.19 dKH. This high sensitivity is what makes both the cancellation and the plateau criterion matter. Temperature compensation is applied per reading by a Nernst relation pHcorr = 7.0+ (pHraw −7.0) (273.15+Tcal)/(273.15+Tmeas), nominally zero-error over 15–35 ℃. Each pH reading is a trimmed mean of 64 samples (discard the top and bottom 16, average the middle 32) to reject aeration-bubble spikes.

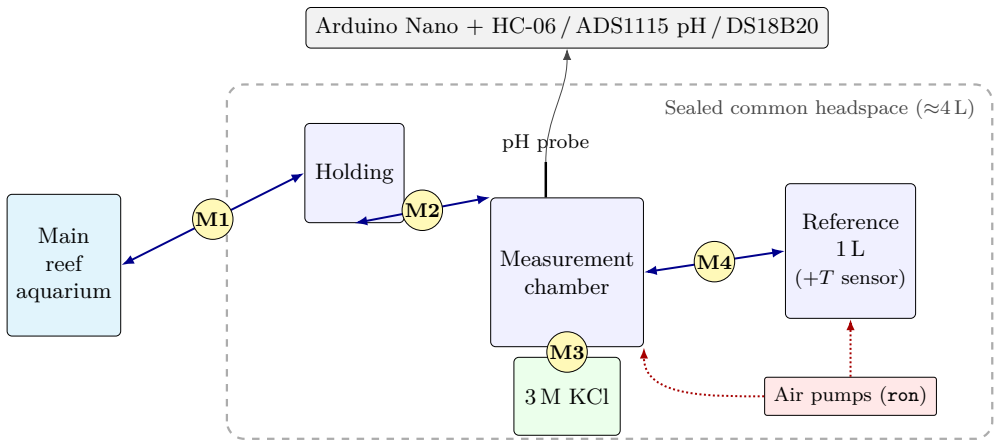
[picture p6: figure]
Sealed common headspace (≈4 L); Main reef aquarium; Holding; Measurement chamber; Reference 1 L; (+T sensor); 3 M KCl; Air pumps (ron); pH probe

Arduino Nano + HC-06 / ADS1115 pH / DS18B20

Figure 1: Schematic of the sealed closed-loop monitor. A single pH probe in the measurement chamber reads the tank aliquot and the reference in turn; four bidirectional peristaltic pumps (M1–M4) move liquid between the main aquarium, holding beaker, measurement chamber, reference reservoir, and KCl store; two air pumps (ron) aerate the reference and the chamber simultaneously. The reference, chambers and pump intakes share one sealed headspace (≈4 L), so sample and reference see identical pCO2
and evaporation is
suppressed; the controller sits outside. Between runs the probe rests in 3 M KCl (M3).

### 3 Apparatus

The build (Table 1, Fig. 1) is a closed fluidic loop around four bidirectional peristaltic pumps, two USB air pumps, a single pH probe, and a 1-Wire temperature sensor, all driven by an Arduino Nano over a 9600-baud Bluetooth (HC-06) serial link to a host PC.

Fluidic topology (current). All pumps are bidirectional (f = forward, b = reverse):
- M1: main aquarium ↔ holding beaker;
- M2: holding ↔ measurement chamber;
- M3: 3 M KCl beaker ↔ measurement chamber (probe soak / storage);
- M4: 5 L reference ↔ measurement chamber.
Routing the tank sample through an intermediate holding beaker lets it be temporarily parked while the reference is measured, minimizing the between-phase delay (Sec. 4). Run times are encoded as the integer in mXf:NN / mXb:NN (seconds); reverse runs ∼8–10 s longer than forward to fully clear the hose (current values m1f:70/m1b:82, m2f:60/m2b:68, m3f:60/m3b:68, m4f:60/m4b:70; the 5 L hose is longest, hence m4b:70).

Control commands. Air and motor enables are independent lines: ron turns both air pumps on (used only while liquid is stationary—bubble cleaning and measurement); ton enables the PWM motor controller (required before any pump will turn); airoff drops both. A load-bearing invariant follows: because airoff also disables the PWM controller, every liquid move must be preceded by airoff → ton; the last air command before a motor must be ton. Measurement primitives are tank / ref (sample and store one pH reading) and calkh (apply Eq. (3)).

Sealed common headspace (required). The 5 L reference, the measurement chamber, and the pump intake share one sealed headspace. This is not an optional refinement: it (i) guarantees tank and ref see identical pCO2

at the instant of measurement (the differential’s premise), (ii) blocks

Table 1: Bill of materials (current build).

Subsystem | Part | Qty
Microcontroller | Arduino Nano V3.0 (ATmega328P) | 1
pH probe | DFRobot Gravity pH V2 (SEN0161-V2), single glass elec- trode | 1
ADC | DFRobot Gravity I²C ADS1115 (16-bit) | 1
Temperature | DS18B20 waterproof (1-Wire), in the 5 L reference | 1
Comms | HC-06 Bluetooth, 9600 baud | 1
Pumps | NKP-DC-B06B 12 V peristaltic, bidirectional (M1–M4) | 4
Motor drivers | L298 2 A modules (2 for pumps, 1 for air) | 3
Air pumps | USB 5 V, switched together (ron) | 2
Reference reservoir | 5 L sealed container (“Wiz tank”) | 1
Chambers | 200 mL beakers: holding, measurement, 3 M KCl | 3
Probe storage | 3 M KCl (≈22 % w/v) | —

room-CO2 excursions at the source, and (iii) suppresses evaporation. In the final configuration the headspace is ≈4 L, the reference ≈1 L, and the tank aliquot 100 mL; an air stone placed in the reference actively pins the shared pCO2 within minutes (the “anchor”, Sec. 4). Separate or isolated headspaces are explicitly forbidden—two headspaces drift independently and destroy the cancellation.

### 4 Methods

### 4.1 Two-phase plateau-following cycle (V4)

Plateau detection is a host-side decision loop, so the PC script drives the firmware step by step. The cycle measures tank first, then ref, so the 5 L reference is co-aerated throughout the tank phase and converges quickly when its turn comes:
1. Prep: m3b (drain KCl from chamber) → m1f (aquarium → holding) → m2f (holding → chamber).
2. Phase A: ron; measure tank every 30 s until plateau (chamber tank + 5 L aerated together).
3. Transition: m2b parks the tank aliquot back in holding; m4f brings reference into the chamber.
4. Phase B: ron; measure ref until plateau (fast—already near equilibrium).
5. calkh; then cleanup: m4b (recover ref to 5 L), m1b (return parked tank to aquarium), m3f (restore KCl soak), airoff (probe rests in KCl).

### 4.2 Two-gate plateau criterion

Readings are held as integer milli-pH (mpH) to avoid floating-point boundary jitter. A plateau is declared only when both gates hold over a sliding window (Table 2): a short span gate (last 4 readings, max − min ≤ 2 mpH) rejects noise, and a longer net gate (last 8 readings, |w−1 − w0| ≤ 1 mpH) rejects a slow monotonic exponential tail that the span gate alone would mistake for convergence. The longer net look-back (8 vs. 4 points; “B1”) was the fix for early latches in which the tank stopped climbing prematurely. Per-phase wall-clock and read-count caps (PHASE_MAX = 7200 s, MEAS_MAX = 240) and a consecutive-failure cap (FAIL_MAX = 5) bound the loop so it can never hang.
Figure 2 shows a measured pair of approach curves. The tank, freshly drawn into the chamber, climbs a slow first-order tail toward its ceiling and is held by the net gate until it is genuinely flat

Table 2: Plateau-following parameters (measure_until_flat).

Constant | Value | Meaning
FLAT_SPAN_N | 4 | span window (jitter gate)
FLAT_SPAN_MPH | 2 | last 4: max − min ≤ 2 mpH
FLAT_NET_N | 8 | net look-back (drift gate; B1)
FLAT_NET_MPH | 1 | last 8: |w−1 − w0| ≤ 1 mpH
MEAS_INTERVAL | 30 s | between readings (aeration continuous)
PHASE_MAX_SECS | 7200 s | per-phase cap (2 h; 4 h total)
MEAS_MAX | 240 | per-phase read cap
FAIL_MAX | 5 | consecutive parse failures tolerated

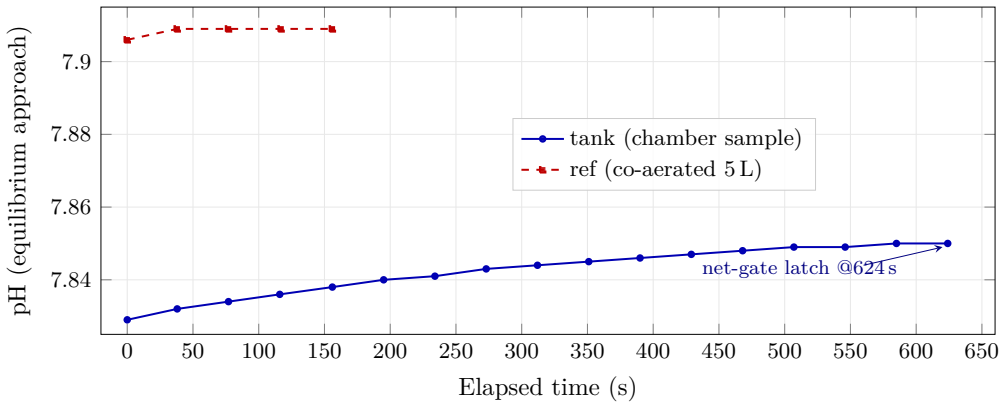
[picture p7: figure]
net-gate; latch @624 s; Elapsed time (s); pH (equilibrium approach); tank (chamber; sample); ref (co-aerated

Figure 2: Measured plateau-following curves (sealed, net-gate run). The tank sample (solid) climbs a slow exponential tail and is latched only when the two-gate criterion (last-4 span ≤ 2 mpH and last-8 net ≤ 1 mpH) is met; the co-aerated reference (dashed) is already near equilibrium and latches quickly. The two series sit at different pH because the underlying samples differ (this run predates the null campaign); only their respective plateau values enter Eq. (3).

(latching at ∼624 s when the 8-point net drift falls to 1 mpH). The reference, having co-aerated in the 5 L reservoir throughout the tank phase, is already at equilibrium and latches in ∼2.6 min—a direct illustration of why measuring tank-first is faster, and of why the span gate alone (satisfied near ∼546 s) would have latched the tank early.

### 4.3 Logging and fault handling

Each completed run appends one line HH ref_pH tank_pH 8.448 tank_kh temp to dkh.dat. Two distinct markers encode abnormal outcomes: an all-zeros line on hard failure (timeout, serial loss, or unverified KCl soak), which additionally latches—a subsequent run refuses to measure and rewrites the marker until a human clears it, protecting the probe from unattended pump cycling; and a negative tank_kh (magnitude preserved, sign flipped) when a phase hits its cap without reaching plateau, which the data server reads as “did-not-plateau” but which does not trip the latch. A finally block runs an emergency cleanup (air off, drain chamber, restore KCl soak) on any non-completion.

Table 3: Method/firmware revisions. “ron held” = continuous aeration between runs.

Rev | Period | Change vs. prior
V0 | 6/14–6/15 | First symmetric build; reference drawn from 5 L into a cup; fixed 1200 s aeration.
V1 | 6/15–6/16 | Added continuous aeration between runs (ron held).
V2 | 6/16–6/17 | Reference taken as a small directly-aerated aliquot (holding → chamber); aeration off during the reading.
V3 | 6/17 | Aeration during measurement (pin tank/ref to same pCO2 ); path symmetrized; KCl-rinse bubble clean (later dropped).
V4 | 6/17→ | Plateau-following to true equilibrium (no fixed time); two-phase tank-then-ref; anti-hang caps; emergency cleanup. Subsequently: sealed common headspace, 5 L active anchor, and the two-gate (B1) criterion.

### 4.4 Null-test protocol

The diagnostic backbone is the null test: the reference and tank vessels are filled with the same water so the true alkalinity difference is zero and the correct output is exactly ∆pH = 0, dKH = 8.448. Two variants are used. In a partial null, only the small tank aliquot is replaced with fresh seawater while the aged 5 L reference is retained, so a change in ∆pH isolates the tank water’s contribution. In a complete null, reference water is also placed in the tank chamber, so the water difference is zero by construction and any residual ∆pH is purely instrumental.

### 4.5 Revision history and the one-change-at-a-time rule

The build evolved through five revisions (Table 3). Changes were made one causal axis at a time, so that each measurement campaign tests a single mechanism; where two constants were changed together (e.g. stabilization window and convergence band), they were justified as the same causal axis (response completeness), not two independent variables.

### 5 Results

Table 4 lists the full campaign. Throughout, ∆pH < 0 means the tank read more acidic than the reference (lower apparent alkalinity), and by Eq. (3) the raw error is dKH−8.448 = 8.448 (10∆pH − 1).

Table 4: Complete measurement campaign (29 runs). “abs pH” is the common-mode level (a room-CO2 proxy within a single day only). Config abbreviations: S = sealed headspace, A = 5 L active anchor, N = net-gate, B1 = net look-back 8. Null staging: a fresh seawater batch is aliquoted at the start; PN = partial null (the 100 mL tank chamber alone is refilled with that fresh aliquot while the aged 5 L reference is kept, isolating the tank-water contribution); CN = complete null (reference water is then transferred into the tank chamber as well, so both vessels hold identical water and the water difference is zero by construction).

# Date/time | Cfg | pHref | pHtank | ∆pH | dKH | T Conditions

1 06-14 20:12 V0 | 7.959 | 8.021 +0.062 | 9.741 | 26.7 first manual symmetric run
2 06-14 21:00 V0 | 7.997 | 8.072 +0.075 | 10.054 | 26.2 —
3 06-15 05:00 V0 | 8.057 | 8.077 +0.020 | 8.843 | 26.4 dawn but +; window open (venti-
| | | | | | lated), low CO2
4 06-15 13:00 V1 | 8.050 | 8.042 −0.008 | 8.293 | 27.0 first continuous aeration

continued on next page

Table 4 (continued)

# Date/time | Cfg | pHref | pHtank | ∆pH | dKH | T Conditions

5 06-15 21:00 V1 | 8.109 | 8.091 −0.018 | 8.109 | 27.3 clean low-CO2 point
6 06-16 05:00 V1 | 7.810 | 7.751 −0.059 | 7.362 | 27.5 dawn closed-room CO2 spike (both
| | | | | | abs pH fell ∼0.3)
7 06-16 13:00 V1b | 8.091 | 8.063 −0.028 | 7.922 | 27.7 tighter window/band
– 06-16 21:00 — | failed (0.000; power cut, port semaphore)
8 06-16 21:21 V2 | 8.042 | 8.021 −0.021 | 8.039 | 28.6 first V2 (manual)
9 06-17 05:00 V2 | 7.997 | 7.939 −0.058 | 7.386 | 27.8 V2 dawn test failed; regressed to V1
10 06-17 13:00 V3 | 8.109 | 8.091 −0.018 | 8.095 | 28.2 first V3; ref under-equilibrated (5
| | | | | | reads)
11 06-17 21:00 V4 | 8.113 | 8.071 −0.042 | 7.669 | 27.8 first V4 + trim-mean firmware; clean
| | | | | | plateaus
12 06-18 05:00 V4 | 7.738 | 7.695 −0.043 | 7.657 | 28.2 decisive: dawn −0.043 ≈ evening
| | | | | | −0.042 despite 0.4 abs-pH swing ⇒ CO2-level independence
13 06-18 13:00 V4 | 8.081 | 8.055 −0.026 | 7.950 | 28.3 same low CO2 as #11 yet −0.026;
| | | | | | dKH +0.29 jump ⇒ baseline not con- stant (evaporation, open 200 mL day 5)
14 06-19 05:00 V4+S | 7.976 | 7.968 −0.008 | 8.283 | 28.1 seal verif.
1 : | dawn dip collapses
| | | | | | −0.05→−0.008; plateau 33→4 reads
15 06-19 13:00 V4+S | 7.957 | 7.947 −0.010 | 8.255 | 28.6 seal verif.
2 : | dawn→noon jump
| | | | | | +0.29 → −0.03 (∼10×); evaporation removed
16 06-19 21:00 V4+S | 7.969 | 7.968 −0.001 | 8.421 | 26.8 near-perfect null (raw err −0.027,
| | | | | | smallest); but +0.166 vs. #14/15 ⇒ offset not a perfect constant; AC tran- sient (−1.8 ℃)
17 06-20 05:00 V4+S | 7.922 | 7.871 −0.051 | 7.521 | 27.7 dawn dip recurs; tank 11× monotone
| | | | | | = early latch (not true plateau); AC cooling slowed kinetics
18 06-20 15:00 V4+SAN | 7.975 | 7.929 −0.046 | 7.602 | 27.1 first 5 L anchor; tank true plateau
| | | | | | (34×, 21.6 min) yet −0.046 ⇒ gen- uine gap, not latch artifact
19 06-20 18:11 V4+S,2× | 7.979 | 7.924 −0.055 | 7.443 | 26.4 controlled exp; 2× aeration halves
| | | | | | climb (1296→711 s) but ∆pH un- changed ⇒ not kinetics
20 06-20 18:57 V4+S,2× | 7.975 | 7.931 −0.044 | 7.636 | 26.7 ref-first + hose swap; gap persists
| | | | | | ⇒ order/path/non-equilibrium all re- jected
21 06-20 19:50 V4+S | 7.975 | 7.926 −0.049 | 7.539 | 26.9 reproduction
22 06-20 20:29 V4+SA | 7.977 | 7.921 −0.056 | 7.426 | 26.9 tank-first+park; ref fastest ever (4×);
| | | | | | tank early latch (7.921) ⇒ motivates B1
23 06-20 21:00 V4+SA,B1 | 7.979 | 7.926 −0.053 | 7.474 | 27.0 B1 ok: tank 25×/945 s true plateau;
| | | | | | confirms #22 was ∼5 mpH short; gap (7th)
24 06-21 05:00 V4+SA,B1 | 7.974 | 7.928 −0.046 | 7.594 | 26.7 dawn matches evening cluster ⇒ time-
| | | | | | of-day dependence ruled out (gap, 8th)
25 06-21 06:00 V4+S,PN | 7.973 | 7.963 −0.010 −8.255 | 26.7 partial null: fresh tank only; tank
| | | | | | pH +37 mpH, ∆pH −0.05 → −0.010; tank not plateaued (old cap) ⇒ lower bound
26 06-21 13:00 V4+S,PN | 7.964 | 7.956 −0.008 | 8.298 | 27.2 partial null, full eq.: dKH 8.298,
| | | | | | raw err −0.15; back in good cluster; 4 h cap validated
27 06-21 19:00 V4+S,CN | 7.960 | 7.957 −0.003 | 8.387 | 27.4 complete null: reference water into
| | | | | | tank chamber too ⇒ both identical; raw err −0.061 = pure instrument off- set; 100 mL vs. 5 L cancels

continued on next page

Table 4 (continued)

# Date/time | Cfg | pHref | pHtank | ∆pH | dKH | T Conditions

28 06-21 21:00 V4+S,CN | 7.959 | 7.958 −0.001 | 8.434 | 27.4 complete null (2nd): ∆pH − 0.001
| | | | | | (resolution limit), raw err −0.014 (smallest); reconfirms the ≤ 0.06 dKH offset
– 06-22 05:00 V4+S,CN | failed (cap) | 55-min scheduler cap killed it mid-ref;
| | | | | | tank had plateaued (7.955); fix: 5 h cap
29 06-22 09:00 V4+S,CN | 7.959 | 7.948 −0.011 | 8.226 | 27.4 aged complete null (∼14 h, 100 mL
| | | | | | exposed aliquot): null decayed to raw err −0.22; tank true plateau 59× (long aeration drives precipitation)

### 5.1 The dawn-CO2 error and its diagnosis

The earliest clear pathology was a dawn collapse of ∆pH (run #6, −0.059; error −1.09 dKH). The decisive clue was common mode: both absolute pH values fell ∼ 0.3 overnight (ref 8.109 → 7.810, tank 8.091 → 7.751), reversing the daytime upward trend—the signature of a closed-room CO2 build-up acidifying the aeration water. A natural experiment confirmed it: on the one ventilated night (run #3, window open) the absolute pH stayed high and ∆pH was a normal +0.020, whereas closed nights gave −0.058/ − 0.059. Crucially, room CO2 is exactly the common-mode variable the differential is supposed to cancel; its leakage into ∆pH signalled a broken ref/tank symmetry, not an environmental problem to be ventilated away.

### 5.2 Plateau-following and the inter-phase drift conflict

Measuring to a true plateau (V4) removed the CO2-level dependence: runs #11/#12 gave ∆pH = −0.042 and −0.043 across a 0.4-unit swing in absolute pH. But the first V4 run had exposed a competing failure: a 31-minute tank measurement whose pH rose to a peak then fell (room CO2 drifting during the measurement), latching at a value set by whenever the single probe happened to sample each vessel. This inter-phase drift, of order

drift ≈ ∆ttank−ref ×

dC
dt , | (5)

sets up a fundamental conflict with a single probe: full equilibrium needs long measurements, but long measurements widen the tank–ref sampling gap ∆t and thus the drift. The same form with dT /dt explains run #16, where an air-conditioner cooling overshoot (−1.8 ℃ during the run) coincided with a +0.166 dKH excursion.

### 5.3 Sealing collapses both confounds

A single sealed common headspace resolves the conflict at the source. By compelling the reference
and tank to share a single common air volume, it makes the common pCO2 | intrinsic rather than
coincidental, blocks room-CO2 excursions, and additionally suppresses the evaporation that had been concentrating the open tank aliquot. The effect was immediate (runs #14/#15): the dawn dip collapsed from −0.05 to −0.008; the dawn→noon dKH jump shrank ∼10× (from +0.29 open to −0.03 sealed); and the plateau time was reduced from ∼33 readings (∼50 min) to ∼4 (∼5 min)— which in turn collapses ∆t in Eq. (5), structurally removing the inter-phase drift. The uncorrected error fell from −0.78 to ∼ −0.18 dKH.

Table 5: Error budget after full diagnosis.

Component | Magnitude | Character / remedy
Aged-tank alkalinity loss | −0.86 dKH | sample handling; use fresh aliquot
Instrument offset | −0.06 dKH | ∆pH = −3 mpH; below correction value
Precision (1σ) | ±0.08 dKH | electrode noise + residual drift
Room-CO2 dependence | ≈ 0 | removed by sealing
Evaporation confound | ≈ 0 | removed by sealing

### 5.4 The active anchor and the persistence of a genuine gap

Sealing alone left a slow headspace drift, because a passive shared air volume re-equilibrates only by surface diffusion (tens of minutes). Placing an air stone in the 5 L reference (the “anchor”) actively pins the shared pCO2 within minutes; a volume audit confirms the dominance hierarchy (sample ∼3 µmol headspace ∼65 µmol 5 L ∼500 µmol). Yet with the anchor and the net-gate in place, a ∼−0.046 to −0.053 gap persisted even when the tank reached a verified true plateau (run #18: 34 readings, 21.6 min). A controlled pair of experiments (runs #19/#20) then rejected, in turn, four device-side explanations: doubling the aeration halved the climb time but left ∆pH unchanged (not kinetics); reversing the measurement order and swapping hoses did not reverse the sign (not order, warm-up, or fluid path); and a tank started from a higher initial pH settled to the same equilibrium (not under-equilibration). The gap was a property of the water.

### 5.5 Null experiments localize the error

Because the device hypotheses were exhausted, we tested the water directly. A partial null (run #25, fresh seawater in the tank chamber only) collapsed ∆pH from −0.05 to −0.010 (tank pH +37 mpH); at full equilibrium (run #26) it gave dKH = 8.298, raw error −0.15—back in the good cluster. Swapping fresh water into the tank had recovered almost the entire error, implicating the aged tank aliquot. The complete null (run #27), with reference water in both vessels so the water difference is zero by construction, returned ∆pH = −0.003, dKH = 8.387, raw error −0.061, with both sides at verified true plateaus despite the 100 mL:5 L volume mismatch—a direct confirmation of volume independence (Sec. 2).

### 5.6 Error decomposition and accuracy

The two nulls decompose the headline error (Table 5, Fig. 3):

−0.92 dKH | | {z | }

raw

= | −0.86 dKH | | {z | }

aged-tank alkalinity loss
(CaCO3 precip./biofilm)
+ −0.06 dKH | | {z | }

instrument offset
(∆pH=−3 mpH)
. | (6)

Across the seven-point cluster (runs #18–24) the precision was ∆pH = −0.0499±0.0048 (≈5 mpH), dKH = 7.531 ± 0.084—a scatter about one-third of the ±0.25 dKH goal. With the bulk error identified as a sample artifact and the instrument offset at −0.06 dKH (one-quarter of the goal), the monitor meets ±0.25 dKH uncorrected; zero-point calibration was judged unnecessary, and with normal (non-degraded) reef water the uncorrected error should fall within ±0.1 dKH.

Raw error | Aged-tank degrade | Instrument offset

−1

−0.5

0

−0.92

−0.86

−0.06

Contribution to error (dKH)

Figure 3: Decomposition of the −0.92 dKH raw error. The complete null isolates the instrument offset at −0.06 dKH (one-quarter of the ±0.25 dKH goal); the partial null attributes the remaining −0.86 dKH to alkalinity loss in the aged tank aliquot (CaCO3 precipitation / biofilm)—a sample artifact, not an instrument fault.

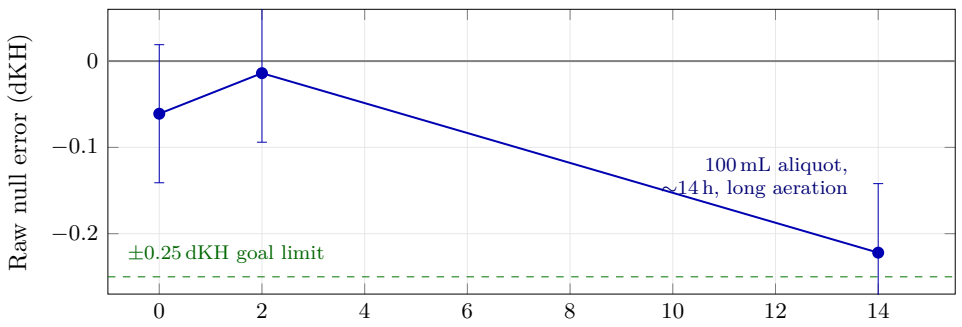
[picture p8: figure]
±0.25 dKH goal limit; aliquot,; ∼14 h, long; aeration; Raw null error (dKH)

Time since first complete null (h)

Figure 4: Time-resolved breakdown of the complete null. With reference water in both vessels (water difference zero by construction), the raw error stays within the ±0.08 dKH precision (error bars) and the ±0.25 dKH goal for the first hours, then falls to −0.22 dKH after the small (100 mL), exposed tank aliquot has aged ∼14 h—a long plateau-following run (59 readings) further driving CaCO3 precipitation during aeration. The electronics are unchanged; only the sample alkalinity drifts, directly confirming that the dominant error term is sample chemistry (cf. Fig. 3).

### 5.7 Time-resolved breakdown of the null

The decomposition makes a falsifiable prediction: if the bulk error is sample chemistry rather than electronics, an otherwise-perfect null should decay as the sample ages. We tested this by re-running the complete null on the same 100 mL aliquot the next day, without touching the instrument (Fig. 4, run #29). The raw error—−0.061 and −0.014 dKH at 0 and 2 h—fell to −0.222 dKH at ∼14 h (∆pH = −0.011; tank pH 7.957→7.948 while the larger reference held at 7.959). The drop is well beyond the ±0.08 dKH precision and was reached at a verified true plateau (tank 59 readings), so it is genuine alkalinity loss, not a latching artifact. The small, exposed aliquot and the unusually long aeration—which raises carbonate saturation and thus drives CaCO3 precipitation during the measurement—are exactly the worst case for the −0.86 dKH mechanism, and the null broke down accordingly while the instrument offset floor stayed at its fresh value. This is the time-domain confirmation of the error decomposition, and a practical caveat: an anomalously long plateau on a small sample is itself a degradation warning.

### 6 Discussion

Implications of the error decomposition. The natural response to a stable ∼ −0.8 dKH offset is to zero-point calibrate. Resisting that—on the methodological principle that a calibration constant should be applied only after independent replication, and never to a small non-independent sample—was decisive, because the offset turned out not to be a constant device property (it varied ±0.085 dKH across the sealed cluster and ultimately proved to be mostly degraded sample water). Calibrating it away would have embedded a sample artifact in the instrument’s calibration and masked the genuine −0.06 dKH floor.

External validation. Our independently derived error structure mirrors published behaviour of the commercial AquaWiz, lending it external support. Community reports identify room-CO2 variation as the dominant error and a sealed container as the field fix; the manufacturer’s own guidance—that a sharp CO2 change “only affects readings for about an hour” and that one should “connect the air intake to the skimmer’s outdoor air line”—matches both our ∼1-hour inter-phase drift episode and our gas-reference-fixing remedy (we realize it by sealing rather than by an outdoor line). The second-most-reported commercial error, bubble-quality degradation from salt creep (> 2 dKH error, clean every six months), matches our aeration-sufficiency analysis. Reported field accuracy (≤ 0.2 dKH vs. a Hanna checker; ≤ 0.75 dKH uncalibrated over seven weeks; “under 0.5 dKH = excellent, use for trend”) brackets our ±0.25 dKH result and our trend-oriented intent. Notably, commercial units are managed by periodic calibration and cleaning and do not pursue a true equilibrium plateau; our plateau-following step extends this further.

Scientific grounding. The kinetic separation underlying the method is well established: the aqueous CO2 hydration/dehydration relaxation completes in ∼16 s [2], so chemistry is never rate-limiting; the slow step is physical gas exchange, ∼15 min for direct bubbling [5], consistent with our observed plateau times. The differential “AT from pCO2

-equilibration plus pH” principle has a recent analytical-chemistry basis demonstrated down to 0.5 mL samples at ±1–2 µmol kg⁻¹ precision [6], supporting small-volume miniaturization as the correct direction.

Limitations. (i) With a single probe the inter-phase drift of Eq. (5) cannot be driven to zero; it is only suppressed (by sealing and by minimizing ∆t). (ii) The dominant historical error was sample degradation, so the operating discipline—use a fresh, adequately sized tank aliquot and recirculate rather than store—is part of the instrument, not an afterthought. (iii) Long plateaus under slow drift can make a measurement run to hours; the wall-clock caps bound this but a hard external scheduler limit must be set above the code’s 4-hour ceiling. (iv) Absolute pH is informative only as a within-day CO2 proxy; only ∆pH is quantitative.

Recommended operation. Seal the common headspace; anchor the reference with active aeration; measure tank-then-ref with the two-gate plateau criterion; use fresh sample water; clean the air path periodically; and treat the output as a trend instrument calibrated, if at all, against an independent kit on a monthly cadence keyed to the ref↔tank divergence.

### 7 Conclusion

A reagent-free, single-probe differential-pH aeration monitor can measure reef carbonate alkalinity to better than ±0.25 dKH without zero-point calibration, once three design rules are observed: a single sealed common headspace, plateau-following to true gas equilibrium, and an actively aerated reference anchor. The value of the eight-day campaign was less in any one number than in decomposing a −0.92 dKH raw error: null experiments showed that −0.86 dKH of it was alkalinity loss in a degraded sample aliquot and only −0.06 dKH was the instrument. The differential design delivered its promised common-mode rejection of room CO2 and probe drift; what remained was chemistry in a beaker, not error in the electronics. We expect the design rules and the null-decomposition methodology to transfer to other low-cost alkalinity instruments.

### Reproducibility

Firmware, the host measurement script (measure_kh_once.py), the raw log (dkh.dat), and the full measurement ledger are available in the project repository [1].

### Acknowledgments

This project was completed thanks to the passion of Mango-miyeok of REEF FAMILY and all the participants of the DIY meetup.

### References

[1] nowforyou (REEF FAMILY), “ReefKeeper: open differential-pH aeration alkalinity monitor (firmware, host scripts, measurement ledger),” project repository, https://github.com/taeseokyi/reefkeeper. (https://github.com/taeseokyi/reefkeeper)
[2] K. S. Johnson, “Carbon dioxide hydration and dehydration kinetics in seawater,” Limnol. Oceanogr. 27(5), 849–855 (1982). doi:10.4319/lo.1982.27.5.0849.
[3] A. L. Soli and R. H. Byrne, “CO2 system hydration and dehydration kinetics and the equilibrium CO2/H2CO3 ratio in aqueous NaCl solution,” Mar. Chem. (2002).
[4] R. E. Zeebe and D. Wolf-Gladrow, CO2 in Seawater: Equilibrium, Kinetics, Isotopes, Elsevier Oceanography Series 65 (2001).
[5] T. Takahashi, “Methods for measurement of pCO2 and total CO2 in seawater” (carbonatesystem methodology; direct-bubbling equilibration ∼15 min).
[6] K. Fleger, X. Liu, W. Berelson, J. Adkins et al., “Total alkalinity measurements in small samples based on CO2 equilibration and spectrophotometric pH,” Anal. Chim. Acta (2025). doi:10.1016/j.aca.2025.344432.
[7] (Gas-stripping first-order equilibration; ln(C0/Ct) ∝ φ/V .) Roberts, Geophys. Res. Lett. (2005).
[8] C. S. Egleston, C. L. Sabine, F. M. M. Morel, “Revelle (buffer) factor of the seawater carbonate system,” Global Biogeochem. Cycles (2010).
[9] Reef-hobbyist community field reports on the commercial AquaWiz alkalinity monitor (room-CO2 error, sealed-container fix, bubble degradation, manufacturer guidance): Reef2Reef threads #1159272, #1073924, #1115439; UltimateReef #939234; Bay Area Reefers #40433.

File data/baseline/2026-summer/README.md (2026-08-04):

# 2026 여름 기준선 스냅샷 (2026-07-04 보관, 2026-08-04 아카이브로 일부 통합)

겨울철 초기 불안정("언덕") 변화를 비교하기 위한 여름 상태 보존본.

## ★2026-08-04: 평탄 이력은 아카이브로 통합됨

이 스냅샷이 생긴 이유는 평탄 이력이 42런=14일 롤링이라 겨울이 되면 여름 커브가 전부
사라진다는 것이었다. **`data/dkh_plateau_archive.jsonl`(append-only, 무기한 보관)이
생기면서 그 이유가 없어졌다** — 여기 있던 `dkh_plateau_history_20260704.json` 10런은
아카이브에 **전 필드 그대로** 들어 있고(검증 완료), 오히려 아카이브 쪽에는 나중에
백필된 `co2_suspect`·`ref_net_mph`가 더 붙어 있다. 두 벌을 두면 갈라지기만 하므로
중복 파일은 제거했다(git 이력에는 남아 있다).

여름 커브를 볼 때는 아카이브에서 기간으로 걸러 쓴다:

```python
import plateau_archive
runs = [r for r in plateau_archive.load() if r["run_started"] < "2026-07-05"]
```

아카이브는 2026-07-01 05:00부터 시작한다(그 이전 커밋 스냅샷이 없어 복원 불가).
**이보다 앞선 기간을 보존해야 하는 계절 스냅샷이 앞으로 생긴다면** 아카이브로는 못
덮으므로 그때는 이 디렉터리 방식이 여전히 필요하다.

## 파일

- `measure_kh_20260701-0704.log` — 같은 기간 원시 측정 로그(V4, 210KB).
  아카이브는 **파싱된 궤적만** 담으므로 `[RAW]` ADC 값·모터 명령·경고 원문 같은 건
  이 로그에만 있다. 그래서 이건 계속 여기 둔다(원본은 1MB 넘으면 덮어써진다).
- ~~`dkh_plateau_history_20260704.json`~~ — 아카이브로 통합, 위 참조.

기억해 둘 런(아카이브에서 같은 run_started 로 찾을 것):

- `2026-07-03 05:00:02` = false lock 사례 원본(tank_n=8에서 조기 잠금, 7.509)
- `2026-07-04 05:00:02` = FLAT_MIN_N_TANK=20 첫 실전 검증 성공(언덕 재현 → n=45 잠금, 7.255)
- `2026-07-02 21:00:03` = BT 사망 미완주 런(completed=False)

## 여름 조건 요약 (비교 기준)

- 실내: 여름(에어컨 유무 혼재), 본수조 26.6°C, 밀폐 챔버 내부 28.9~30.5°C → 시료 **+2.8°C 승온** 과도
- 진짜 평형 tank pH: 7.816~7.819 (나흘 연속 사실상 고정)
- 진폭(시작pH−평형pH): 낮 99~123 mpH / 새벽 35~38 mpH (새벽=저진폭=false lock 취약)
- 초기 언덕: 첫 1~7샘플 평탄(span ≤1 mpH)한 뒤 하강 시작하는 형태, 방향은 하강(승온+CO₂ 동방향)
- tank 잠금 소요: 정상 45~78샘플(29~50분), ref: 8~15샘플
- 도징: 올포리프 자동 2mL×6/일(유지 수준), ref_kh 앵커 8.830

## 겨울에 볼 것

챔버 온도 하강 → ΔT 부호 반전(시료가 식는 쪽) 가능 → 열(상승)·CO₂(하강) 과도가 반대 방향이 되면
n=20 이후 "중턱 어깨"(기울기 0 통과)형 false lock 위험 — MIN_N 게이트가 못 막는 유일한 모양.
겨울 데이터를 이 스냅샷과 같은 형식으로 비교할 것.

**★주의(2026-07-23 측정 방식 전환):** 이 기간은 "폭기 중 전체측정" 구 스킴이고, 7/23부터는
"고정 사전폭기(tank 25분/ref 3.5분) + 읽는 순간만 폭기 OFF"로 바뀌었다. flat_n·곡선 모양을
7/23 이후 런과 직접 비교하면 안 된다.

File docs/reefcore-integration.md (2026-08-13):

# reefCore 생태계 연동 — AquaWiz dKH 올리기

> 관련 문서: [프로젝트 개요 (README)](../README.md) | [자동화 구성](system-setup.md) | [측정 대장](measurement-ledger.md)

AquaWiz(reefWiz)가 측정한 **탄산경도(dKH)** 를 **reefCore 생태계**의 내 체커(reefChecker)에 측정값으로 올리는 연동입니다. 2026-06-23 메커니즘 검증·실측 성공.

> ⚠️ **자격증명·시크릿은 이 문서에 값으로 적지 않습니다.** 모두 환경변수명으로만 표기하며, 공개 저장소에 실제 값을 커밋하지 않습니다.

## 1. 생태계 구성

| 구성요소 | 역할 |
|---|---|
| **reefCore** | 허브/클라우드 (앱·계정·DB). 사이트 `reef.anih.net` (React SPA) |
| **reefChecker** | Hanna Checker HC 비색계 기반 ESPHome 기기 (dKH/Ca/Mg/NO3/PO4/pH 측정) |
| **reefWiz** | 본 프로젝트(AquaWiz). dKH를 위 생태계로 공급 |

## 2. 아키텍처

- **REST API**: `https://reefapi.anih.net`. 인증 `POST /auth/login {email, password}` → JWT(`Authorization: Bearer …`).
- **측정값 주입 경로**: 현재 채택 경로는 **기기가 MQTT로 발행 → 백엔드가 수집**. (정정 2026-06-25: 과거 "REST 생성 엔드포인트 없음"이라 적었으나, 실제로는 `POST /devices/{mac}/measurements {mode,value,unit,temp,measured_at,memo}`(ManualMeasurementRequest)가 **존재**한다. 이 경로는 retain 자체가 없어 유령 중복 위험이 없고 `measured_at` 을 명시할 수 있는 **더 깔끔한 대안**이나, REST 인증(JWT)이 필요하다. 현 conf 자격은 **MQTT 전용**(`/mqtt/auth` 로 검증)이라 `/auth/login` 에는 401 — 웹 계정 비번이 있어야 전환 가능. 미채택, 향후 옵션.)
- **MQTT 브로커**: `reef.anih.net:8883` (MQTT over TLS). 여러 기기가 쓰는 **공유 브로커**.
- **MQTT 인증**: reefCore **계정 자격** 사용 — username = 계정 이메일(`$REEFCORE_USER`), password = 계정 비번(`$REEFCORE_PASS`).
- **기기 등록**(참고): `POST reefapi.anih.net/devices/register {mac, email, device_type}`. `device_type` ∈ `reefcore`/`checker`/`ato`/`module`. 펌웨어에 박힌 등록 키(`$REEFCORE_REG_KEY`)로 인가하는 것으로 추정.

## 3. dKH 올리는 메커니즘 (검증됨)

체커는 ESPHome 표준 토픽으로 상태를 발행합니다:

```
reefcore-checker-<mac6>/sensor|select|switch|number/<엔티티>/state
```

이 중 **"최근 측정값" 센서 토픽**에 아래 형식의 요약 문자열을 발행하면, 백엔드가 이를 파싱해 `{mode, value, unit, temp, measured_at}` 측정 레코드를 생성합니다:

```
토픽   : reefcore-checker-<mac6>/sensor/________________/state
                                  └ 한글 엔티티명이 sanitize되어 언더스코어로 보임
페이로드: "<mode>: <value> <unit> | <temp>°C @ <YYYY-MM-DD HH:MM>"
예시    : "dKH: 8.43 dKH | 27.2°C @ 2026-06-23 13:39"
```

- 발행 시 **고유 client_id**(`reefwiz-*`)를 쓰면 체커의 MQTT 세션을 끊지 않습니다.
- 대상 체커 MAC은 `$REEFCORE_MAC`(기본값=내 체커)로 지정. 토픽의 `<mac6>`는 MAC 끝 6자리.

## 4. 구현 — 수동 발행 도구 `bin/reefcore_bridge.py`

> **★2026-08-12 변경: 측정 스크립트의 자동 발행 제거(사용자 지시).**
> 이전에는 `measure_kh_once.py` 가 `dkh.dat` 기록 직후 `publish_to_reefcore()` 로 측정당 1회
> 자동 발행했다. 지금은 그 코드(`publish_to_reefcore`·`_publishable`·`_reefcore_creds`)가
> **측정 소스에서 완전히 제거**됐다 — 측정은 `dkh.dat` 기록까지만 하고 reefCore 로 아무것도
> 보내지 않는다. `C:\dkh\reefcore.conf` 나 paho 설치 여부와도 무관해졌다.
> 발행이 필요하면 아래 브리지를 **수동으로** 실행한다.

`bin/reefcore_bridge.py` 가 같은 MQTT 발행을 1회 실행하는 독립 도구다(디버그·보충용).

- **best-effort**: 자격 미설정·paho 미설치·연결 실패 등에서 조용히/우아하게 끝난다.
- 발행은 **`retain=False`**·`qos=1`, 고유 client_id(`reefwiz-*`)라 체커 세션을 끊지 않는다.
  - ⚠️ **`retain=False` 가 중요하다.** 이 토픽은 단순 상태가 아니라 "수신 시 측정 레코드를 생성"하는 이벤트 토픽이라, `retain=True` 면 브로커가 보관한 옛 측정값을 **백엔드 재접속 때마다 재전달 → 유령 중복 레코드**를 만들 수 있다. 백엔드는 상시 접속(`/debug/state` 의 `mqtt_connected:true`)이라 `retain=False` 여도 발행이 정상 도달한다(2026-06-25 실측: retain=False 발행 후 `/debug/state` 의 '최근 측정값' 토픽이 즉시 갱신됨). 과거 `retain=True` 로 남았던 retained 메시지는 빈 retained 발행으로 클리어 완료.

자격증명은 **환경변수**(`$REEFCORE_USER`/`$REEFCORE_PASS`/`$REEFCORE_MAC`)로 준다.

## 5. 참고 — dKH 값 규약

`dkh.dat` 의 수조 dKH 는 **양수=정상 측정, 음수=평탄 미도달, 0=측정 에러**(V4 규약)다.
브리지로 수동 발행할 때는 이 규약을 아는 값만 올리는 편이 안전하다 — reefCore 백엔드가
음수/0 dKH 를 파싱·저장한다는 보장은 없다.

## 6. 보안 / 운영 주의

- **자격증명은 환경변수로만.** `$REEFCORE_USER`/`$REEFCORE_PASS`를 코드·문서·저장소에 값으로 남기지 않습니다(저장소 public).
- **브로커 인증서 만료**: 포트별로 인증서가 다르다. **웹(443)은 갱신됨**(Let's Encrypt YE2, ~2026-08-31)이나 **MQTT 브로커(8883)는 별개 인증서로 2026-05-03 만료** 상태(브로커가 갱신본을 안 물고 옛 인증서로 기동 중인 전형적 케이스). 따라서 브리지는 현재 `tls_verify=0`(CERT_NONE)로 접속. 운영자가 8883 브로커에 갱신 인증서 적용+리로드하면, conf 에 `tls_verify=1` 만 추가해 검증 ON(재배포 불요). ※KISTI 등 SSL 검사 게이트웨이(swg.*)는 보통 443만 가로채고 8883은 통과시키므로, 브라우저가 보는 "유효"는 웹(443) 인증서다.
- 공유 브로커라 구독 시 본인 체커 토픽(`reefcore-checker-<mac6>/#`)으로 한정하세요. (참고 2026-06-25: 브로커는 `POST /mqtt/auth`·`/mqtt/acl`·`/mqtt/superuser` HTTP 훅으로 인증/ACL을 백엔드에 위임하는 구조 — MAC 토픽 격리가 실제로 ACL로 강제될 여지가 있다(미검증). 다만 `GET /debug/state` 는 **인증 없이 전체 기기명 목록과 내 체커 전 토픽 상태를 노출**한다(자가 검증엔 유용했으나 정보 노출 면은 운영자 영역).)

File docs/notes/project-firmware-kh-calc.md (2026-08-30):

# project-firmware-kh-calc

> 펌웨어 dKH 차동 계산식과 ref_pH/tank_pH 상승=전극 드리프트 진단

---

펌웨어: `firmware/reefwiz_meter_m1/reefwiz_meter_m1.ino` (Arduino Nano, ATmega328P). README.md에 위치 명시.

**dKH 계산식 (`calcAndSaveKH`, 차동 방식):**
```c
deltaPH = refPH - tankPH;
tankDKH = refDKH * pow(10.0, -deltaPH);   // refDKH = EEPROM 앵커
```
- **dKH는 ΔpH(refPH-tankPH)에만 의존, 절대 pH는 수학적으로 상쇄됨.**
- `ref_kh`가 dkh.dat에서 매 행 고정인 이유 = EEPROM 기준 앵커(`REF_DKH_ADDR`, `calref`로 갱신). 측정값 아님.
- **★앵커 이력: 8.448은 측정 테스트용 임의값(정확값 아님, 사용자 6/29). 첫 실교정 = 2026-06-29 calref로 한나체커 7.000 기준 앵커=8.830 EEPROM 저장.** 검산: 8.830×10^(7.786−7.886=−0.1)=7.01 ✓. 교정 후 독립 검증 3행 6.957/6.935/6.993(평균 6.96, span0.065)=목표 충족. → 8.448→8.830 "+0.38 점프"는 드리프트/증발 아니라 임의값→첫 실교정일 뿐.
- pH는 단일 프로브(ADS1115+DFRobot_PH)가 참조수→수조수 순차 측정, `nernstPH()` 온도보상, slope/offset은 EEPROM 캘리 고정.

**ref_pH/tank_pH 단조 상승 진단 (확정):**
- 참조·수조 pH가 매 사이클 0.001 이내로 같이, 시간당 ~+0.01씩 매끈하게 상승 = **pH 유리전극 장기 드리프트**(막 비대칭전위 + KCl 기준전극 junction 노화). 공통모드 → 원인은 공통 프로브 1개. 수질 변화 아님.
- 참조수(고정 기준액)까지 똑같이 오르는 게 결정적 증거. 온도는 반대로 내려갔음.
- 가끔의 하강 리셋(예: 4.282→4.181)은 재캘리브레이션(`enterph`/`calph`/`exitph`)·전극 재안정화 이벤트.
- **dKH 신뢰도 영향 없음**: 차동식이 절대 pH 드리프트를 상쇄 → tank_kh 8.45 안정 유지. README도 "pH 프로브 반복성=전체 오차 97%"라 명시, 차동 설계가 이 드리프트 대응책.

**Why:** dkh.dat에서 ref_kh 고정·pH 단조상승이 정상인지 묻는 질문이 반복됨. 코드로 검증한 결론.

**How to apply:** "pH 왜 오르나" → 전극 드리프트로 설명, dKH는 무영향. 절대 pH 필요하거나 드리프트 과대 시 `calph` 재캘(pH4/7), KCl junction 점검, 장기적 프로브 교체. ΔpH 보존돼도 절대 pH가 ADS1115 입력범위/readPH 선형구간 벗어날 위험은 주기적 재캘로 방지. 관련: [project-measure-kh-script](project-measure-kh-script.md)

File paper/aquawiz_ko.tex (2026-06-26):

\documentclass[11pt]{article}

% ---- arXiv 스타일 프리프린트 (XeLaTeX + 한글) ----
\usepackage[margin=1in]{geometry}
\usepackage{amsmath,amssymb}
\usepackage{graphicx}
\usepackage{booktabs}
\usepackage{array}
\usepackage{multirow}
\usepackage{longtable}
\usepackage{caption}
\usepackage{authblk}
\usepackage{xcolor}
\usepackage{enumitem}
\usepackage{textcomp}
\usepackage{mhchem}
\usepackage{siunitx}
\sisetup{detect-all}
\usepackage{pgfplots}
\pgfplotsset{compat=1.15}
\usetikzlibrary{arrows.meta,positioning,calc}
\usepackage{kotex}
\usepackage{fontspec}
\setmainhangulfont{NanumMyeongjo}
\setsanshangulfont{NanumGothic}
\usepackage[hidelinks]{hyperref}

\captionsetup{font=small,labelfont=bf}
\renewcommand{\arraystretch}{1.15}

% 편의 매크로
\newcommand{\dpH}{\ensuremath{\Delta\mathrm{pH}}}
\newcommand{\dkh}{\ensuremath{\,\mathrm{dKH}}}
\newcommand{\co}{\ensuremath{\mathrm{CO_2}}}
\newcommand{\pco}{\ensuremath{p_{\mathrm{CO_2}}}}
\newcommand{\at}{\ensuremath{A_\mathrm{T}}}

\title{\bfseries 해수 탄산알칼리니티 측정을 위한 저가형 단일프로브\\
차동 pH 폭기 모니터: 계통오차 분해와 밀폐 공통 헤드스페이스\\
평형화를 통한 0.25\,dKH 이하 정확도 달성}

\author[1]{nowforyou\thanks{교신: \texttt{taeseokyi@gmail.com}}}
\affil[1]{REEF FAMILY}

\date{\today}

\begin{document}
\maketitle

\begin{abstract}
\noindent
탄산알칼리니티(이하 ``KH'', 단위 \dkh)는 산호 어항에서 가장 제어가 중요한
수질 인자이지만, 저렴한 연속 모니터는 드물고 시약 적정은 번거롭다. 본 논문은
시료를 대기 \co{}와 평형에 이를 때까지 폭기한 뒤 도달한 평형 pH로부터
알칼리니티를 추정하는 무시약(reagent-free) 개방형 모니터를 기술한다. \emph{단일}
pH 프로브로 어항 시료(``tank'')와 알칼리니티가 알려진 참조수(``ref'')를 연달아
측정한다. dKH가 두 pH의 \emph{차}로 계산되므로
($\mathrm{KH_{tank}} = \mathrm{KH_{ref}}\cdot 10^{\dpH}$), 프로브의 절대
드리프트와 실내 \co{} 변동은 공통모드 신호로서 상쇄된다. 9일간의 계측 캠페인
(5개 펌웨어/방법 버전에 걸친 30회 측정)에서 무보정 오차 $-0.92\dkh$가 지속적으로
관찰되었으며, 우리는 이를 영점 보정으로 지우는 대신 \emph{분해}하였다. 세 가지
개입---(i) 진짜 가스 평형까지 가는 평탄 추종 측정, (ii) 시료ㆍ참조수ㆍ펌프 흡입이
공유하는 단일 \emph{밀폐 공통 헤드스페이스}, (iii) 헤드스페이스 \pco{}를 고정하는
능동 폭기 5\,L 참조수 앵커---이 새벽 \co{} 오차와 일주기 증발 교란을 붕괴시켰고
측정 산포를 $\mathrm{SD}=\pm0.08\dkh$ (목표 $\pm0.25\dkh$의 약 1/3)로 줄였다.
이어진 널 실험(두 용기에 동일한 물, 참값 $\dpH=0$)이 잔차를 국소화하였다:
\emph{완전 널}에서 $\dpH=-0.003$, $\mathrm{dKH}=8.387$, 즉 계측 오프셋은 단
$-0.06\dkh$에 불과했다. 남은 $-0.86\dkh$는 수일 된, 소부피, 개방 상태의 tank
분취액에서 일어난 알칼리니티 손실(\co{} 과포화에 의한 \ce{CaCO3} 석출/생물막)로
추적되었다---이는 측정 결함이 아니라 시료 취급 아티팩트다. 같은 노화 분취액으로 하루
에 걸쳐 널을 재측정하니 전자장치를 건드리지 않았는데도 널이 0에서 멀어지며 연속 측정에서
$-0.22$, 이어 $+0.22\dkh$로 드리프트하는 것을 관찰하여, 이 귀속을 시간 영역에서 확증하였다. 따라서 본 장치는 영점
보정 없이 $\pm0.25\dkh$ 목표를 달성하며, 영점 보정은 불필요한 것으로 판정되었다.
우리가 독립적으로 도출한 오차 구조(실내 \co{} 민감도, 기포 품질 의존성, 해법으로서의
밀폐)는 상용 제품의 보고된 거동을 그대로 재현하여, 진단과 해법 양쪽에 외부 검증을
제공한다.
\end{abstract}

\noindent\textbf{키워드:} 산호 어항; 탄산알칼리니티; 총알칼리니티; \co{} 평형화;
차동 pH; 저가 계측; 공통모드 제거; \ce{CaCO3} 석출.

% =====================================================================
\section{서론}
% =====================================================================
경산호를 비롯한 석회화 생물은 탄산칼슘을 침착시키며 탄산알칼리니티를 끊임없이
소모한다. 닫힌 산호 어항에서 이 알칼리니티 감소는 빠르며(흔히
$0.5$--$1.5\dkh\,\mathrm{day^{-1}}$), $\sim1\dkh$를 넘는 변동은 산호 조직 스트레스와
연관된다. 알칼리니티(\at{}, 취미가들은 보통 독일식 도 단위의 ``KH''로 표기,
$1\dkh \approx 0.357\,\mathrm{meq\,L^{-1}}$)는 따라서 \emph{자주} 측정할 가치가
가장 큰 인자다.

접근 가능한 선택지는 연속 사용에 부족하다. 수동 시약 적정(예: 상용 드롭 키트)은
정확하지만 노동집약적이고 이산적이다. 색도 로봇은 적정을 자동화하지만 시약을
소모하고 비싸다. 직접 전위차 pH 단독은 \emph{알칼리니티 측정이 아니다}. 해수 pH는
\at{}와 \pco{}에 함께 의존하고, 어항 \pco{}는 하루 동안 크게 변하기 때문이다(실내
환기, 광합성, 호흡).
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

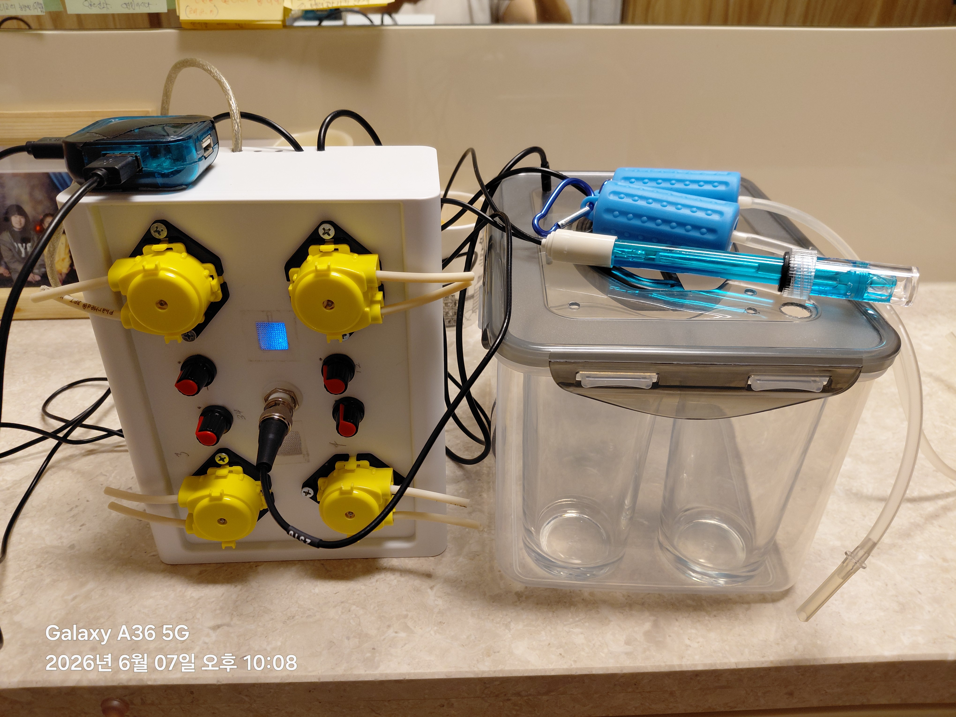
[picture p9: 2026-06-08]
docs/images/완성한 실물.jpg

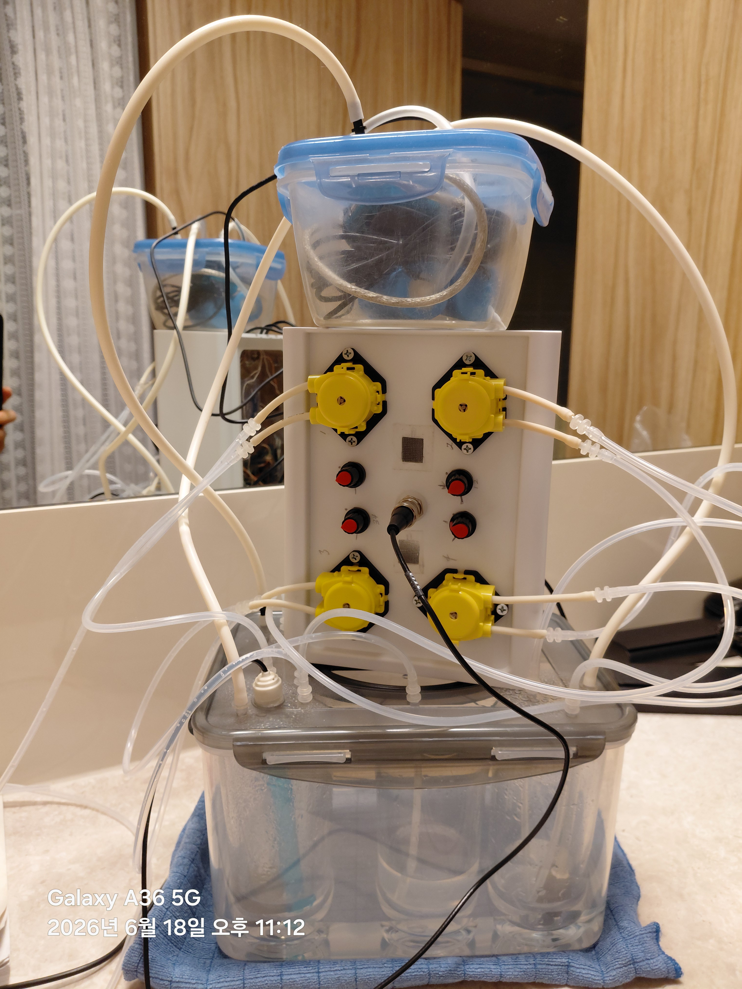
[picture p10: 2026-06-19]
docs/images/Sealed_Closed_Loop_Aqua_Whiz_Final_Product.jpg

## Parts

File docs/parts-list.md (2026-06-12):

# AquaWiz 준비물 목록

> 관련 문서: [프로젝트 개요 (README)](../README.md) | [자동화 환경 구성](system-setup.md) | [사용 설명서](user-manual.md)

## 디바이스마트

| # | 사진 | 부품명 | 수량 | 금액 |
|---|---|---|---|---|
| 1 |  | <a href="https://www.devicemart.co.kr/goods/view?no=15315999" target="_blank">아두이노 나노 호환보드 V3.0 CH340 C타입</a> | 1 | 5,500원 |
| 2 |  | <a href="https://www.devicemart.co.kr/goods/view?no=14592629" target="_blank">Gravity: I2C ADS1115 16-Bit ADC Module</a> | 1 | 23,000원 |
| 3 |  | <a href="https://www.devicemart.co.kr/goods/view?no=14593211" target="_blank">Gravity: Analog pH Sensor/Meter Kit V2</a> | 1 | 57,500원 |
| 4 |  | <a href="https://www.devicemart.co.kr/goods/view?no=1278835" target="_blank">2A L298 모터드라이버 모듈 (아두이노 호환)</a> | 3 | 8,100원 |
| 5 |  | <a href="https://www.devicemart.co.kr/goods/view?no=1376882" target="_blank">블루투스 모듈 HC-06 (DIP) 펌웨어 v1.8</a> | 1 | 5,500원 |
| 6 |  | <a href="https://www.devicemart.co.kr/goods/view?no=1321161" target="_blank">5V 고정 출력 강하형 DC-DC 3A 컨버터</a> | 1 | 3,500원 |
| 7 |  | <a href="https://www.devicemart.co.kr/goods/view?no=1345967" target="_blank">PWM 12V 2A DC모터 속도 제어 컨트롤러</a> | 4 | 8,000원 |
| 9 |  | <a href="https://www.devicemart.co.kr/goods/view?no=1322408" target="_blank">브레드보드 830핀 MB-102</a> | 1 | 1,400원 |
| | | **디바이스마트 소계** | | **124,320원** |

## AliExpress

| # | 사진 | 부품명 | 수량 | 금액 |
|---|---|---|---|---|
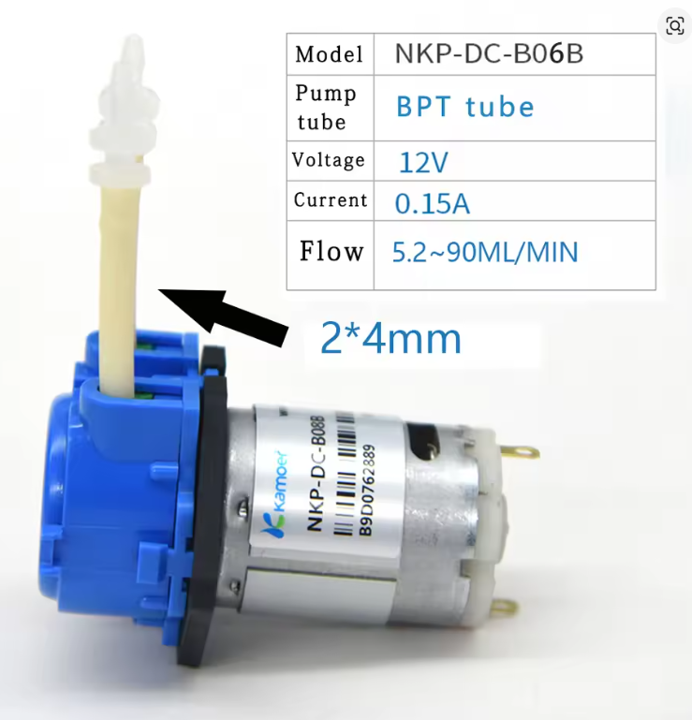
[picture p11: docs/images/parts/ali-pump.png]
| 10 |  | <a href="https://www.aliexpress.com/item/1005001888639071.html" target="_blank">연동 펌프 NKP-DC-B06B (12V, yellow)</a> | 4 | ₩21,680 |
| | | **AliExpress 소계** | | **₩21,680** |

## 별도 구매 필요 부품

### 전자부품

| # | 부품명 | 사양 | 수량 | 용도 |
|---|---|---|---|---|
| 11 | DS18B20 방수 온도센서 | PTFE 케이블, 1-Wire | 1 | Nernst 온도 보상 (위즈 탱크 침수) |
| 12 | <a href="https://smartstore.naver.com/vim/products/4583133452" target="_blank">USB 5V 에어 펌프</a> | DC 5V, USB 전원 | 2 | 참조수/수조수 폭기 (L298N3 제어) |
| 13 | 세라믹 콘덴서 100nF (104) | 50V 이상 | 4 | C1: Arduino, C2: ADS1115 VDD, C3: 아날로그 입력 RC필터, C4: DS18B20 |
| 14 | 저항 330Ω (주황-주황-갈색-금) | 1/4W | 1 | ADS1115 아날로그 입력 RC 필터 직렬 저항 (R6) |
| 15 | 저항 4.7kΩ (노랑-보라-빨강-금) | 1/4W | 1 | DS18B20 풀업 저항 (R2) |
| 16 | 저항 10kΩ (갈색-검정-주황-금) | 1/4W | 1 | HC-06 TX 전압분배기 (R4) |
| 17 | 저항 20kΩ (빨강-검정-주황-금) | 1/4W | 1 | HC-06 TX 전압분배기 (R5) |
| 18 | 12V DC 어댑터 | 12V 3A 이상 | 1 | 전체 시스템 전원 |
| 19 | DC 잭 (배럴커넥터) | 5.5x2.1mm | 1 | 어댑터 연결용 |
| 20 | 점퍼 와이어 | M-M, M-F 혼합 | 1세트 | 브레드보드 배선 |

### 비전자 부품 (실험 환경)

| # | 부품명 | 사양 | 수량 | 용도 |
|---|---|---|---|---|
| 21 | 실리콘 에어 스톤 | 수족관용 | 2 | 에어 펌프 출력단 기포 분산 |
| 22 | 실리콘 호스 | 내경 2~4mm | 적량 | 펌프/에어 연결 |
| 23 | 비이커 | 200ml | 3 | 수조물 / pH 측정 / 3M KCl |
| 24 | 위즈 탱크 용기 | 다이소 락앤락 김치통 (5L) | 1 | 참조 해수 + 비이커 수납 (아래 참고) |
| 25 | 3M KCl 용액 | - | 적량 | pH 프로브 저장수 (건조 방지) |
| 26 | pH 보정 버퍼 용액 | pH 4.0 / pH 7.0 | 각 1 | pH 2점 보정 |

## 총 합계

| 구매처 | 금액 |
|---|---|
| 디바이스마트 | 124,320원 |
| AliExpress | 21,680원 |
| 별도 구매 | 미정 |
| **주문 합계** | **146,000원** |

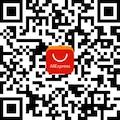
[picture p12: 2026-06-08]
docs/images/parts/ali-pump.webp

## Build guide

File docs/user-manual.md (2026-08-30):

# AquaWiz 사용 설명서 v2.0

**고정밀 pH / 경도(dKH) 측정 시스템**

> 관련 문서: [프로젝트 개요 (README)](../README.md) | [자동화 환경 구성](system-setup.md) | [준비물 목록](parts-list.md) | [측정 대장](measurement-ledger.md) | [reefCore 연동](reefcore-integration.md) | [블루투스 재연결](bt-reconnect-and-testing.md)

| 항목 | 내용 |
|---|---|
| 측정 공식 | `KH_tank = KH_ref * 10^(-DeltaPH)` |
| 블루투스 통신 | HC-06 하드웨어 Serial D0/D1 (9600 baud) |
| 플래시/RAM | 약 90% / 약 58% (Arduino Nano ATmega328P) — `seq`/`wait`/`air` 레거시 제거로 여유 확보 |
| 전위 산출 | 64샘플 **트림평균** (정렬 후 상·하위 각 16개 버리고 중앙 32개 평균 → 폭기 버블 스파이크 제거) |
| dKH 이력 | 최근 5개 (RAM, 전원 OFF 시 소멸) |

---

## 1. 시스템 개요

### 1.1 측정 원리

> 탈기 후 두 샘플의 CO2 농도가 동일해지면, pH 차이(DeltaPH)는 순수하게 알칼리니티(dKH) 차이만을 반영합니다.

```
[CO2] = 3 x KH x 10^(7-pH)
KH_tank = KH_ref x 10^(-DeltaPH)
DeltaPH = pH_ref - pH_tank
```

- `DeltaPH > 0` : 수조 pH가 참조보다 낮음 → 수조 dKH 낮음
- `DeltaPH < 0` : 수조 pH가 참조보다 높음 → 수조 dKH 높음

### 1.2 하드웨어 구성

| 부품 | 모델 | 역할 |
|---|---|---|
| MCU | Arduino Nano V3.0 (ATmega328P) | 메인 컨트롤러 |
| pH 센서 | DFRobot SEN0161-V2 | pH 전압 측정 |
| ADC | Adafruit ADS1115 | 16비트 I2C ADC (A4/A5) |
| 온도 센서 | DS18B20 | 1-Wire 온도 측정 (A0=D14) |
| 블루투스 | HC-06 | 하드웨어 Serial D0/D1 (9600baud) |
| 모터 드라이버 | L298N x 3 | L298N1/N2: 도징 펌프 4개 (12V), L298N3: 에어 펌프 (5V) |

### 1.3 핀 배치

| 핀 | 연결 | 설명 |
|----|---|---|
| D0 (RX) | HC-06 TX | 블루투스 수신 (직결) |
| D1 (TX) | HC-06 RX | 블루투스 송신 (전압분배기: R4 10k + R5 20k) |
| D4~D7 | L298N1 IN1~IN4 | 모터1/2 제어 |
| D8~D11 | L298N2 IN1~IN4 | 모터3/4 제어 |
| D12 | L298N3 IN2 | 에어 펌프 ON/OFF (`ron`/`roff`) |
| D13 | L298N3 IN4 | PWM 속도 제어기 ON/OFF (`ton`/`toff`) |
| A0 (D14) | DS18B20 DQ | 1-Wire 온도센서 |
| A4 | ADS1115 SDA | I2C 데이터 |
| A5 | ADS1115 SCL | I2C 클럭 |

> **주의:** 업로드 시 HC-06을 D0/D1에서 반드시 분리하세요. 분리하지 않으면 업로드가 실패합니다.

### 1.4 블루투스 터미널 앱

안드로이드 스마트폰에서 블루투스 시리얼 통신으로 AquaWiz를 제어합니다.

**추천 앱:**  <a href="https://play.google.com/store/apps/details?id=de.kai_morich.serial_bluetooth_terminal" target="_blank">Serial Bluetooth Terminal</a> (Kai Morich, 무료)

- HC-05, HC-06 등 Bluetooth Classic SPP 지원
- 시리얼 터미널 방식으로 명령 입력/응답 확인
- 매크로 기능으로 자주 쓰는 seq 명령 등록 가능
- 평점 4.6, 100만+ 다운로드

**연결 방법:**
1. 안드로이드 설정 → 블루투스 → HC-06 페어링 (PIN: 1234)
2. Serial Bluetooth Terminal 앱 실행
3. 좌측 메뉴 → Devices → HC-06 선택 → Connect
4. 9600 baud 자동 인식, 명령 입력 시작

---

## 2. 초기 설정

### 2.1 pH 2점 보정

> **주의:** 가장 먼저 수행해야 합니다. 보정값은 EEPROM에 저장되어 전원 OFF 후에도 유지됩니다.

| 단계 | 명령 | 설명 |
|---|---|---|
| 1 | `enterph` | 보정 모드 진입 |
| 2 | `calph` | pH 7.0 버퍼 용액 삽입 → 자동 인식 후 보정 |
| 3 | `exitph` | 보정값 EEPROM 저장 후 종료 |
| 4 | `enterph` | 다시 진입 |
| 5 | `calph` | pH 4.0 버퍼 용액 삽입 → 자동 인식 후 보정 |
| 6 | `exitph` | 보정값 EEPROM 저장 후 종료 |

### 2.2 온도 오프셋 설정

표준 온도계와 DS18B20의 차이값을 설정합니다. EEPROM에 저장됩니다.

```
settemp:-0.3
```

DS18B20 오프셋 설정 (예: 표준 25.0도, DS18B20 25.3도 → -0.3 입력). 범위: -10.0 ~ 10.0도.

설정 즉시 raw 온도와 보정 후 온도를 출력하여 확인할 수 있습니다.

### 2.3 참조 dKH 설정

참조 해수의 알칼리니티를 dKH로 입력합니다. EEPROM에 저장됩니다.

```
setref:8.5
```

참조 해수 dKH 설정 (범위: 0.5 ~ 30.0 dKH). 자연 해수 일반값은 약 7~8 dKH입니다. 실측값 사용을 권장합니다.

---

## 3. 측정 방법

### 3.1 표준 측정 절차

> **주의:** 참조수와 수조수를 동일 공간에서 30분 이상 동시 탈기 후 측정해야 정확합니다.

| 단계 | 명령 | 설명 |
|---|---|---|
| 1 | `settime:HH` | 현재 시(0~23) 설정 (이력 타임스탬프용, 예: `settime:14`) |
| 2 | `ref` | 참조수 pH 측정 (약 8초, 64회 오버샘플링) — RAM 저장 |
| 3 | `tank` | 수조수 pH 측정 (약 8초) |
| 4 | `calkh` | dKH 계산 + 결과 출력 + 이력 저장 |

> 참조수 pH는 RAM에만 저장됩니다. 전원 ON 후 매번 `ref` 명령을 실행해야 합니다.

### 3.2 자동 측정 (PC 연동)

> **변경(현재 펌웨어):** 측정 전 고정 사전폭기로 시료를 평형 근처까지 올린 뒤 **진짜 평형(평탄)까지** 반복 측정해야 하므로(평탄 판정 = 측정값 비교 후 반복 결정, 기포기 모터 노이즈 차단을 위해 각 read 직전에만 폭기를 끔), 자동화는 PC측 파이썬 스크립트가 담당합니다. 펌웨어의 `seq`/`seqstop`/`wait`/`air` 명령은 **제거**되었습니다. 단발 테스트는 위 §3.1처럼 `ref`/`tank`/`calkh`를 직접 입력하거나 모터/에어 명령을 수동 전송하면 됩니다.

PC측 자동 측정 스크립트:

```bash
# 1회 측정 후 종료 (Windows 작업 스케줄러 정시 호출 / 수동 실행 가능)
python bin/measure_kh_once.py        # 포트 = 기본값 COM9
python bin/measure_kh_once.py COM7   # 포트 직접 지정

# ref dKH 교정(역산) — 알려진 수조 dKH 로 참조수 dKH 를 거꾸로 보정
python bin/measure_kh_once.py --setref 8.448         # 수조 실측 8.448 dKH 기준
python bin/measure_kh_once.py COM7 --setref 8.448    # 포트 지정 + 교정
```

스크립트가 준비 → **[A] tank·ref 동시 폭기 + tank 평탄까지** → 전이 → **[B] ref 평탄까지** → `calkh` → 정리 순으로 펌웨어 명령을 단계별 전송합니다. 상세 흐름·상수·스케줄러 등록은 [자동화 환경 구성 — 자동 측정 시퀀스](system-setup.md#자동-측정-시퀀스-pc-측-v4)를 참조하세요.

**`--setref` (calref 모드, ref dKH 역산):** 인자를 주지 않으면 평소처럼 `calkh`(수조 dKH 측정 → `dkh.dat` 기록)를 수행합니다. `--setref <수조실측dKH>` 를 주면 동일한 tank·ref pH 측정 후 `calkh` 대신 **`calref`** 를 호출해 **참조수 dKH 를 역산·EEPROM 저장**합니다. 절차: ① 명령라인 수조 dKH 를 `setref` 로 기록(측정 전 범위 0.5~30.0 즉시 검증) → ② tank·ref pH 측정(동일) → ③ `calref` 가 `newRefDKH = 수조dKH · 10^(−(tankPH−refPH))` 를 계산하고 `refDKH` 에 대입 + EEPROM 저장(펌웨어가 자동 저장하므로 추가 `setref` 불요). 보정은 일회성이라 **`dkh.dat` 에는 기록하지 않습니다.** 위즈 참조수 같은 알려진 표준액으로 수조를 채워 측정하면, 그 값을 기준으로 참조수 dKH 앵커를 교정할 수 있습니다.

### 3.3 calkh 결과 출력

```
===[dKH]===
시각:14   참조pH:8.350   수조pH:8.201   dPH:0.1490   refKH:8.50 dKH   수조KH:6.012 dKH   온도:25.0C
===========
```

- ppm, meq/L, 상태 표시는 제거되었습니다. dKH 값으로 직접 판단하세요.
- 산호 수조 권장 범위: **8 ~ 12 dKH**

### 3.4 status 출력 예시

```
=== 상태 ===
시각:14
온도:25.30C 오프셋:-0.30 보정T:25.0C
수조pH:8.201
참조pH:8.350
dPH:0.1490
refKH:8.50 dKH
수조KH:6.012 dKH
KH이력:2개
[M1] 정지
[M2] 정지
[M3] 정지
[M4] 정지
[직접] 에어(D12):OFF PWM(D13):OFF
============
```

| 항목 | 설명 |
|---|---|
| 온도 / 오프셋 / 보정T | 현재 수온, DS18B20 오프셋, pH 보정 시 온도 (Nernst 기준) |
| [M1]~[M4] | 모터 상태 — 동작 중이면 잔여 시간 표시 |
| [직접] 에어(D12) / PWM(D13) | D12(에어 펌프)·D13(PWM 속도 제어기) 핀 ON/OFF 상태 |

> 구 펌웨어의 `[대기]`(wait)·`[SEQ]`(seq) 표시는 해당 명령 제거와 함께 사라졌습니다.

### 3.5 calref — 참조 dKH 역산

참조 해수의 dKH를 직접 측정하기 어려운 경우, 수조수의 dKH(상용 테스트킷 실측값)를 기준으로 참조수의 dKH를 역으로 계산합니다.

```
1. setref:8.5          ← 수조 dKH 실측값 (상용 테스트킷)
2. ref                 ← 참조수 pH 측정
3. tank                ← 수조수 pH 측정
4. calref             ← 참조 dKH 역산 + EEPROM 저장
```

**계산 공식:**

```
newRefDKH = 수조dKH × 10^(-(tankPH − refPH))
```

> 참고: calref의 `dPH`는 `tankPH − refPH`로, calkh/§1.1의 ΔpH(`refPH − tankPH`)와 부호가 반대입니다. calref는 calkh의 역산(참조 dKH를 거꾸로 구함)이라 부호가 뒤집힌 것이며, 결과는 서로 일관됩니다.

**출력 예시:**

```
===[calref]===
  시각:14
  참조pH:8.350
  수조pH:8.201
  dPH:-0.1490
  새refDKH:11.985 dKH
  수조dKH:8.50 dKH
  온도:25.0C
===============
[OK] refDKH 저장:11.985 dKH
```

> 이후 `calkh`로 측정하면 저장된 refDKH를 기준으로 수조 dKH를 자동 계산합니다. 이력은 저장하지 않습니다.

---

## 4. 명령어 전체 참조

### 4.1 pH 측정 명령

| 명령 | 설명 |
|---|---|
| `settime:HH` | 현재 시 설정 (0~23, 예: `settime:14`) — 이력 타임스탬프용 |
| `ref` | 참조수 pH 측정 → RAM 저장 (전원 OFF 시 소멸, 매번 측정 필요) |
| `tank` | 수조수 pH 측정 |
| `calkh` | dKH 계산 + 출력 + 이력 저장 (최대 5개) |
| `calref` | 수조 dKH 기준으로 참조 dKH 역산 + EEPROM 저장 (아래 참고) |
| `setref:xx.x` | 참조 dKH 설정 [EEPROM] (예: `setref:8.5`, 범위: 0.5~30.0) |
| `settemp:xx.x` | 온도 오프셋 설정 [EEPROM] (예: `settemp:-0.3`, 범위: +/-10.0) |
| `khhist` | dKH 이력 조회 (최신순 5개, 번호/시각/dKH) |
| `status` | 현재 전체 상태 출력 (아래 참고) |
| `ver` | 기기 버전 한 줄 출력 (`ReefWiz Meter M-1 v1.0.0 #커밋코드`, `#` 뒤는 펌웨어 커밋 코드) |

| `help` | 명령어 도움말 출력 |

### 4.2 pH 보정 명령

| 명령 | 설명 |
|---|---|
| `enterph` | 보정 모드 진입 — 버퍼 용액에 프로브 삽입 후 안정화 |
| `calph` | pH 4.0 / 7.0 자동 인식 후 보정 |
| `exitph` | 보정값 EEPROM 저장 후 종료 |

### 4.3 펌프 모터 명령

| 명령 | 설명 |
|---|---|
| `m1f:초` | 모터1 정방향 N초 (예: `m1f:10`, 범위: 1~3600초) |
| `m1b:초` | 모터1 역방향 N초 |
| `m1s` | 모터1 즉시 정지 |
| `m2f:초` / `m2b:초` / `m2s` | 모터2 (L298N1 채널B) |
| `m3f:초` / `m3b:초` / `m3s` | 모터3 (L298N2 채널A) |
| `m4f:초` / `m4b:초` / `m4s` | 모터4 (L298N2 채널B) |

> PC측 측정 스크립트는 각 모터 명령의 완료 응답(`[모터N] 완료`)을 받은 뒤 다음 단계로 진행합니다.

### 4.4 에어 / PWM 공급 명령

| 명령 | 설명 |
|---|---|
| `ron` | D12 HIGH — 에어 펌프 ON (참조수+수조수 폭기) |
| `roff` | D12 LOW — 에어 펌프 OFF |
| `ton` | D13 HIGH — PWM 속도 제어기 ON (도징 펌프 구동 전 활성화) |
| `toff` | D13 LOW — PWM 속도 제어기 OFF |
| `airoff` | D12·D13 동시 LOW — 에어 + PWM 제어기 둘 다 OFF |

> `ron`/`roff`로 에어 펌프(D12)를, `ton`/`toff`로 PWM 속도 제어기(D13)를 독립적으로 켜고 끕니다. `airoff`는 두 핀을 한 번에 LOW로 내립니다.
> **하드웨어 규칙:** 액체 이동(`mXf`/`mXb`) 직전에는 반드시 `airoff`로 폭기를 끄고, 펌프 구동 전 `ton`으로 PWM 제어기를 켭니다.
> 구 펌웨어의 `air:총초:주기초`(교대 폭기) 명령은 **제거**되었습니다.

### 4.5 정지 명령

| 명령 | 설명 |
|---|---|
| `m1s`~`m4s` | 해당 모터 개별 즉시 정지 |
| `stop` | 전체 모터 정지 + 에어/PWM 핀 OFF (motorAllStop + stopAir) |

> 구 펌웨어의 `seq`/`seqstop`(시퀀스 매크로)·`wait:`(대기) 명령은 **제거**되었습니다. 자동 측정은 PC측 스크립트가 담당합니다(§3.2).

---

## 5. dKH 측정 이력

### 5.1 이력 구조

| 항목 | 내용 |
|---|---|
| 저장 위치 | RAM (전원 OFF 시 소멸 — EEPROM 미사용) |
| 최대 개수 | 5개 (라운드 로빈 — 6번째부터 가장 오래된 것 덮어쓰기) |
| 저장 항목 | 시각(HH), dKH |
| 타임스탬프 | `settime:HH` 설정값 기준 경과 시간 자동 보정 |

### 5.2 khhist 출력 형식

```
[KH이력] 5개
1  14  8.52
2  12  8.48
3  10  7.93
4  08  8.61
5  06  8.55
```

- 번호 1이 가장 최신, 번호가 클수록 오래된 값입니다.
- `settime` 미설정 시 시각은 `??`로 표시됩니다.

---

## 6. EEPROM 저장 항목

| 항목 | 저장 위치 | 비고 |
|---|---|---|
| pH 보정값 (pH4/7 전압) | `0x00~0x07` | DFRobot_PH 라이브러리 자동 관리 |
| 참조 dKH (`setref`) | `0x10~0x13` | 전원 OFF 후에도 유지 |
| 온도 오프셋 (`settemp`) | `0x14~0x17` | 전원 OFF 후에도 유지 |
| pH 보정 온도 (`exitph`) | `0x18~0x1B` | Nernst 보정 기준 온도, 보정 시 자동 저장 |
| 참조수 pH 전압 (`ref`) | RAM만 | 전원 ON 후 매번 측정 필요 |
| dKH 측정 이력 (`calkh`) | RAM만 | 전원 OFF 시 소멸 |

---

## 7. 오류 메시지 안내

| 메시지 | 조치 |
|---|---|
| `[ERR] ADS1115 실패!` | ADS1115 I2C 배선(A4/A5) 확인 후 재시작 |
| `[WARN] DS18B20 없음!` | DS18B20 배선(A0) 및 4.7k 풀업저항 확인 |
| `[WARN] DS18B20 오류→25C` | 온도 센서 일시 오류, 25도로 pH 계산 진행 |
| `[WARN] ref 없음→ref 실행` | `ref` 명령으로 참조수 측정 필요 |
| `[WARN] refDKH 없음→setref` | `setref:xx.x` 명령으로 참조 dKH 입력 필요 |
| `[ERR] tank 미측정` | `tank` 명령 실행 후 `calkh` 실행 |
| `[WARN] dKH 이상` | pH 보정 재실행 또는 참조 dKH 확인 |
| `[ERR] 모터시간 1~3600초` | 1~3600초 범위로 재입력 |

---

## 8. 사용 팁

### 8.1 정확한 측정을 위한 필수 조건

1. **밀폐 공통 헤드스페이스(필수):** 참조수 통·측정 챔버·펌프 흡입을 **하나의 밀폐 공기**로 묶습니다. ref·tank가 같은 한 덩어리 공기를 공유해야 측정 순간 pCO₂가 일치하고 방 CO₂ 변동이 차동으로 상쇄됩니다. **분리 밀폐 금지**(서로 다른 밀폐 공간은 따로 드리프트해 상쇄가 깨짐). 증발 차단 효과도 함께 얻습니다. → [밀폐 공통 헤드스페이스](system-setup.md#위즈-탱크)
2. **사전폭기 + 평형까지 측정:** 참조수와 수조수를 같은 공기로 동시에 폭기하고, V4는 측정 전 고정 사전폭기(tank 25분·ref 3.5분)로 평형 근처까지 올린 뒤 tank·ref가 각각 진짜 평형(평탄)에 도달할 때까지 반복 측정합니다(기포기 모터 노이즈를 피하려 각 read 직전에만 폭기를 끄고, 샘플 사이는 다시 폭기해 평형을 유지). 밀폐로 평형 기준(헤드스페이스 pCO₂)이 고정돼 있어 "뚜껑 닫고 한 번 측정"이 아니라 **고정된 평형으로 끌고 가 공통모드 상쇄**가 깨끗하게 일어납니다.
3. **온도 보정:** `settemp`로 DS18B20 오프셋을 설정하면 pH 계산 정확도가 높아집니다.
4. **pH 보정:** 월 1회 pH 4.0/7.0 버퍼 용액으로 2점 보정을 실시합니다.
5. **ref 재측정:** 전원 ON 후 반드시 `ref` 명령으로 참조수를 다시 측정해야 합니다(수동 측정 시).
6. **업로드:** HC-06을 D0/D1에서 분리한 후 업로드하고, 완료 후 다시 연결합니다.

### 8.2 산호 수조 권장 dKH 범위

| 범위 | dKH | 비고 |
|---|-----|---|
| 자연 해수 | 약 6.5~7.5 | 참조 기준 |
| 산호 수조 권장 | 8 ~ 12 | 일반적 권장 |
| SPS 산호 최적 | 8 ~ 9 | 경산호류 |
| LPS/소프트 코랄 | 7 ~ 11 | 연산호류 |

---

## 9. 웹 대시보드

측정 결과는 GitHub Pages 대시보드에서 확인합니다: **<https://taeseokyi.github.io/reefwiz/>** (PWA — 브라우저의 "설치"로 앱처럼 사용 가능)

| 카드 | 내용 |
|---|---|
| 최신 dKH | 마지막 측정값·시각 |
| dKH 그래프 | 최근 3일 / 7일 / 전체 기간 토글 — 회차 수가 아니라 **날짜**로 자릅니다(측정이 빠지거나 더 돌아간 날이 있어도 창은 정확히 N일). 날짜는 `dkh.dat` 에 직접 기록됩니다(2026-08-16~) |
| 평탄 추종 | 최근 14일치 평탄 수렴 곡선(하루 3회면 42런, 날짜 기준 보관) — 런 선택 드롭다운 + ◀▶ 이동, 말미 확대 |
| 도저 자동 조정 | 조정 이력·권고와 수동 설정·목표 설정 (§10) |

- **데이터 흐름:** Windows 측정 완료 직후 래퍼(`run_measure_and_sync.py`)가 WSL의 `sync_dkh_dat.py`를 호출 → git push → GitHub Actions(`make_dkh_json.py`) → Pages 반영. 측정 종료 후 수 분 내 갱신됩니다.
- **최신값 JSON API:** 측정 PC의 `dkh_server.py`가 `GET /api/dkh`(포트 9999)로 마지막 측정값을 제공합니다. 외부에서는 `http://tsyi.homeip.net:9999/api/dkh` (※같은 네트워크의 WSL 내부에서 외부 URL 접근은 NAT 루프백 문제로 실패할 수 있음).
- **reefCore 연동:** 측정 스크립트의 자동 발행은 **제거**됐습니다(2026-08-12). 필요할 때 `bin/reefcore_bridge.py`로 수동 발행합니다 → [reefCore 연동](reefcore-integration.md)

---

## 10. 도저 자동 조정 (올포리프)

메인 수조(250L)의 dKH를 목표값으로 유지하기 위해, 측정 결과를 바탕으로 올포리프(AFR) 도징량 조정을 계산합니다(`bin/doser_adjust.py`).

### 10.1 동작 개요

- **매일 1회(13시 측정 후)** 권고를 계산합니다(2026-07-11부터 주말 포함). 현재 **자동 적용은 꺼짐(권고 전용)** — 계산·기록만 하고 도저 설정은 바꾸지 않습니다. 수동 설정·목표 저장은 이와 무관하게 계속 적용됩니다.
- 도저 하드웨어: 1회 도즈 = 펌프 8초 = 2mL, 하루 6회(4시간 간격). 통에는 **50% 희석액**을 담으므로 실도징(펌프가 뿜는 부피)은 원액 환산의 2배입니다.

### 10.2 조정 개념 — 오차와 속도

- **오차(수준):** 현재 dKH = **최근 유효 측정 3회의 중앙값**과 목표의 차이. 하루 3회 측정이라 정확히 24시간 창 — 야간 CO₂ 편향 같은 하루 주기 극단값 1개는 중앙값이 걸러냅니다.
- **속도(추세):** **최근 7일 측정의 기울기**(Theil-Sen 중앙값 기울기, 튀는 값에 강함) — 지금 도징으로 dKH가 하루에 움직이는 속도입니다. 7일은 회차 수(21회)가 아니라 **날짜**로 세고, 기울기도 실제 측정 시각 간격으로 계산합니다(2026-08-16~). 측정이 빠진 날이 있어도 창이 과거로 늘어나지 않고, 하루에 더 측정한 날이 있어도 창 안쪽이 밀려나지 않습니다.
- **조정 원리:** 필요한 속도(오차÷7일)에서 현재 속도를 뺀 만큼만 도징량을 변경합니다 — 이미 목표 쪽으로 움직이고 있으면 그만큼 덜 바꿉니다(속도 보상).
- **목표 접근:** 오차를 **7일**에 걸쳐 좁히되, dKH 변화 속도 상한은 **±0.25 dKH/일**(허용 오차 ±0.5의 절반)입니다.

### 10.3 안전 한계

| 항목 | 값 |
|---|-----|
| 1회 조정 폭 | 현재 도징량의 최대 ±30% |
| 도징량 절대 범위 | 원액 1.5~18.0 mL/일 (실도징 3~36 mL/일, 펌프 2000~24000ms) |
| 데드밴드 | 원액 0.15 mL/일(200ms) 미만 차이는 유지 |
| 감도 가정 | 원액 1 mL/일 ≈ +0.006 dKH/일 (6/29 볼루스 55mL→+0.32 dKH 실측 유도) |
| 중단·보호 | 최근 7일 유효 측정 10점 미만이면 조정 안 함 · 적용 실패 시 이전값 롤백 · 수동 설정이 있는 회차는 자동 조정 생략 |

### 10.4 대시보드에서 수동 설정·목표 설정

- **수동 설정(원액 1.5~18 mL/일):** 도저 카드의 입력란에 값을 넣고 "수동 설정"을 누르면 GitHub에 커밋되고, 측정 PC의 폴러가 **최대 ~5분 내** 도저에 적용합니다. 수동 설정이 있는 회차는 자동 권고를 생략합니다.
- **목표 설정(6.0~9.0 dKH, 기본 7.2):** 저장 즉시가 아니라 **다음 자동 조정 회차(매일 13시)부터** 반영됩니다.
- 두 기능 모두 첫 사용 시 **GitHub 토큰**(fine-grained, 이 저장소 Contents 읽기/쓰기)을 입력해야 하며, 토큰은 해당 기기 브라우저에만 저장됩니다.

---

펌웨어 빌드, 필수 라이브러리, 업로드 절차는 [README — 빌드 및 업로드](../README.md#빌드-및-업로드)를 참조하세요.

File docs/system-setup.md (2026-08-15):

# AquaWiz 자동화 환경 구성

> 관련 문서: [프로젝트 개요 (README)](../README.md) | [사용 설명서](user-manual.md) | [준비물 목록](parts-list.md) | [측정 대장](measurement-ledger.md)

## 실물 사진

| 제어기 |
|:---:|
| 제어기 |

### 최종 형태 — 밀폐 폐루프 (공통 헤드스페이스)

> 참조수 통(5L)·측정 챔버·펌프 흡입을 **하나의 밀폐 공기**로 묶은 최종 구성입니다. 측정 순간 ref·tank가 같은 pCO₂를 공유해 방 CO₂ 변동을 차동으로 상쇄하고, 증발도 차단합니다. **밀폐는 선택이 아니라 필수** — 근거·검증은 아래 [위즈 탱크](#위즈-탱크)와 [측정 대장](measurement-ledger.md)(2026-06-19) 참조.

## 시스템 구성도

시스템 구성도

## 호스 연결

호스 연결도

## 준비물

구매 링크 포함 상세 목록은 [준비물 목록](parts-list.md)을 참조하세요.

## 하우징 (3D 프린팅)

| 제어기 하우징 | 펌프 + 에어 분배기 하우징 |
|:---:|:---:|
| 제어기 | 펌프+분배기 |
| 180 x 173 x 45mm | 296 x 53 x 75mm |
| <a href="../hardware/housing/controller-box.scad" target="_blank">OpenSCAD 도면</a> | <a href="../hardware/housing/pump-air-box.scad" target="_blank">OpenSCAD 도면</a> |

OpenSCAD 파라메트릭 설계 — 부품 실측 후 상단 파라미터만 수정하면 치수 자동 조정됩니다.

## 구성 요소

### 제어기 본체

| 구성 | 사양 |
|---|---|
| MCU | Arduino Nano V3.0 (ATmega328P) |
| pH 센서 | DFRobot SEN0161-V2 + ADS1115 16bit ADC |
| 온도 센서 | DS18B20 (위즈 탱크 내 침수) |
| 통신 | HC-06 블루투스 (9600 baud) |
| 모터 드라이버 | L298N1/L298N2 (도징 펌프, 12V) + L298N3 (에어 펌프, USB 5V) |
| 속도 제어 | PWM 컨트롤러 Motor− 출력 → L298N ENA/ENB (역 PWM) |
| 전원 | 12V DC → Buck 5V (MCU) + USB 5V (L298N3 에어 펌프) |

### 연동 펌프 (4구, 모두 양방향)

| 펌프 | 경로 | 정방향 (f) | 역방향 (b) |
|---|---|---|---|
| 펌프1 (M1) | 수조 ↔ 수조물 비이커 | 수조 → 수조물 비이커 (샘플링) | 수조물 비이커 → 수조 (반환) |
| 펌프2 (M2) | 수조물 비이커 ↔ pH 측정 비이커 | 수조물 → pH 비이커 (측정 이송) | pH 비이커 → 수조물 (측정 후 반환) |
| 펌프3 (M3) | 3M KCl 비이커 ↔ pH 측정 비이커 | KCL → pH 비이커 (프로브 보관) | pH 비이커 → KCL 비이커 (저장수 배출) |
| 펌프4 (M4) | 위즈 탱크 ↔ pH 측정 비이커 | 참조수 → pH 비이커 (측정 이송) | pH 비이커 → 위즈 탱크 (참조수 반환) |

### 에어 공급 및 PWM 속도 제어 (L298N3)

| 핀 | 명령 (ON / OFF) | 용도 |
|-----|---|---|
| D12 (L298N3 채널A) | `ron` / `roff` | USB 5V 에어 펌프 ON/OFF (참조수 + 수조수 폭기) |
| D13 (L298N3 채널B) | `ton` / `toff` | PWM 속도 제어기 ON/OFF (모터 구동 시 활성화) |
| D12 + D13 | `airoff` | 둘 다 LOW (에어 OFF + PWM 제어기 OFF) |

- `ron`/`roff`: D12 → 에어 펌프 ON/OFF (참조수·수조수 동시 탈기)
- `ton`/`toff`: D13 → PWM 속도 제어기 ON/OFF (도징 펌프 구동 전 `ton`)
- `airoff`: D12·D13 동시 LOW (둘 다 OFF). 전체를 한 번에 끄려면 `stop`(모터 전체 + 에어/PWM 핀)
- **하드웨어 규칙:** 액체 이동(`mXf`/`mXb`) 직전에는 반드시 `airoff`로 폭기를 끈다.

> **참고:** 구 펌웨어의 `air:총초:주기초`(교대 공급) 명령은 **제거**되었고, 독립 OFF용 `roff`/`toff`와 전체 정지 `stop`이 추가되었습니다.

### 위즈 탱크

| 항목 | 사양 |
|---|---|
| 용기 | 다이소 락앤락 김치통 (5L) |
| 내용물 | 참조 해수 (알려진 dKH 값) |
| 센서 | DS18B20 온도 센서 침수 |
| 비이커 | 200ml x 3개 (수조물, pH 측정, 3M KCl) |

모든 비이커는 위즈 탱크 안에 담겨 있어 참조수와 동일한 온도 환경을 유지합니다.

> ## ★밀폐 공통 헤드스페이스 — 선택이 아니라 필수
>
> **참조수 통·측정 챔버·펌프 흡입을 *하나의 공통* 밀폐 공기로 묶습니다(폐루프 흡입).** 차동식 `KH_tank = KH_ref × 10^(−ΔpH)`이 순수 KH차를 주려면 측정 순간 ref·tank가 **같은 pCO₂**여야 하는데, 밀폐 공통 헤드스페이스는 두 물이 *같은 한 덩어리 공기*를 공유하게 해 이 조건을 **본질적으로 보장**합니다.
>
> 1. **방 CO₂ 변동 차단(핵심):** 외부 공기를 끊으므로 방 CO₂가 ΔpH로 새어들 통로가 없어집니다. 차동 상쇄가 가장 잘 일어나는 조건.
> 2. **증발 차단:** 측정수의 증발 농축(경도 상승)을 막아 ΔKH=0 전제를 지키고 참조수 dKH도 장기간 일정하게 유지합니다.
> 3. **온도 균일:** 밀폐 공간 내 참조수·수조수·KCL이 동일 온도로 유지되어 Nernst 보정 정확도가 향상됩니다.
>
> **★필수 조건 — 분리 밀폐 금지.** ref와 tank가 **서로 다른** 밀폐 공간에 있으면 두 헤드스페이스가 따로 드리프트해 상쇄가 깨집니다. 반드시 **하나의 공통 헤드스페이스**를 공유해야 합니다. 펌프 흡입도 외기가 아니라 이 공통 공기에서 폐루프로 끌어옵니다.
>
> **검증(2026-06-19):** 밀폐 적용 후 첫 새벽(고-CO₂) 측정에서 그간 3회 재현되던 새벽 오차(ΔpH −0.043~−0.059)가 **−0.008**로 붕괴했습니다(낮 baseline 수준). 또 헤드스페이스가 참조수 알칼리니티 버퍼로 핀고정돼 평형이 사실상 즉시 도달(과거 새벽 33회 → 4회, 측정 ~50분 → ~5분) → tank↔ref 측정 시간차가 붕괴해 드리프트성 오차까지 구조적으로 사라졌습니다. 무보정 원시오차도 −0.78 → −0.165 dKH로 줄어 목표 정확도 안에 들어왔습니다. 상세는 [측정 대장](measurement-ledger.md).
>
> **주의:** 펌프 발열이 헤드스페이스/수온을 밀어올릴 수 있으므로 온도욕조 안정과 응결을 점검하세요(6/19 측정은 28.1℃로 폭주 없음).

## 노이즈 대책

노이즈 제거 콘덴서 배치도

## 자동 측정 시퀀스 (PC 측 V4)

### 설계 배경 — 평형 추종 (사전폭기 + 노이즈 차단 측정)

차동식 `KH_tank = KH_ref × 10^(−ΔpH)`이 순수 KH차를 반영하려면 측정 순간
ref·tank가 **같은 pCO₂**여야 합니다. 이를 두 축으로 달성합니다.

1. **밀폐 공통 헤드스페이스(필수, 가스 기준 고정):** ref·tank가 하나의 밀폐 공기를
   공유하므로 *같은 pCO₂*가 본질적으로 보장되고 방 CO₂ 변동 통로가 차단됩니다 →
   [위즈 탱크 — 밀폐 공통 헤드스페이스](#위즈-탱크) 참조.
2. **고정 사전폭기 + 노이즈 차단 측정(2026-07-23~):** 측정 *전* 시료를 고정 시간
   폭기(tank 25분·ref 3.5분)해 평형 근처까지 올린 뒤, 평탄 판정을 위해 반복 측정합니다.
   ★기포기 모터의 전기 노이즈가 pH 읽기에 간섭하므로 **각 측정값을 읽는 순간에만**
   폭기를 끄고 10초 정치한 뒤 읽고(모터 노이즈 소산), **샘플 사이 유휴 구간은 다시
   폭기**해 평형을 계속 붙듭니다(측정 내내 끄는 방식이 아니라 read 시점만 off).
   두 물을 같은 평형(천장)으로 끌고 가는 원리는 그대로입니다.

밀폐가 평형의 기준(헤드스페이스 pCO₂)을 고정하므로 평형 추종은 *움직이는* 천장이
아니라 *고정된* 천장을 향하게 되어, 측정 시간차(gap)에 따른 드리프트 오차까지
사라집니다. (근거·실측은 [측정 대장](measurement-ledger.md) 참조: 6/18 개방 셋업의
ΔpH −0.042/−0.043가 방 CO₂ 스윙과 무관하게 일정함을 보였고, **6/19 밀폐 적용 후
새벽 ΔpH가 −0.008로 붕괴**해 새벽 오차가 제거됨.)

- **평탄 판정**: `tank`/`ref`를 30초 간격으로 반복(각 read 직전에만 폭기 off + 10초
  정치)하며 **최근 4개의 정수 milli-pH (max−min) ≤ 2 mpH**(흔들림, span) **AND 최근
  8개 양끝차 ≤ 1 mpH**(드리프트, net)면 평형으로 보고 종료합니다. 정수 비교라 float
  지터가 없고, net 룩백이 span보다 길어 느린 단조 꼬리에 조기 종료되지 않습니다.
- **2-phase**: **[A]** tank·ref 동시 폭기 + tank 평탄까지(ref는 홀딩 챔버에서
  co-aeration) → 전이(무대기) → **[B]** ref 평탄까지(co-aeration이라 평형 근처서
  시작 → 빨리 수렴).
- **무한 대기 방지**: phase별 최대 *측정* 시간 `PHASE_MAX_SECS=5400`s(=90분, 사전폭기
  제외), 최대 횟수 `MEAS_MAX=180`, 연속 측정실패 `FAIL_MAX=5`, 시리얼 read 타임아웃.
  미평탄 상한 도달 시 마지막값 채택 + 경고(`dkh.dat`에 음수 표식).
- **트림평균 전위**: 펌웨어가 64샘플을 정렬해 상·하위 16개를 버리고 중앙 32개만
  평균 → 폭기 버블 스파이크 제거(차동이라 절대 pH만 미세 변동, dKH 무영향).
- **프로브 보관액 3M KCl**: 측정 외 상시 소크가 곧 컨디셔닝이라 별도 재생 루틴
  불필요. 중성염이라 잔류(캐리오버)가 dKH에 무영향 → V4는 헹굼 단계 생략.

### 전체 흐름 (measure_kh_once.py)

배관(2026-06-20): `m1`=본수조↔홀딩, `m2`=홀딩↔측정챔버, `m3`=KCl↔측정챔버,
`m4`=참조수(5L 위즈수조)↔측정챔버. **측정 순서 = tank 먼저 → ref 나중** —
tank 측정 내내 5L 위즈수조를 *동시 폭기*해 ref 가 5L서 co-aeration → ref 차례엔
이미 평형 근처라 빨리 수렴합니다. (헹굼 단계는 V4에서 제거됨.)

```
── 준비 ──────────────────────────────────────────
  airoff → ton
  ① m3b:68  KCl 보관액 배출 (측정 챔버 비우기)
  ② m1f:70  본수조수 → 홀딩 챔버
  ③ m2f:60  홀딩 → 측정 챔버 (tank 측정수 채움)

── [A] tank 평탄까지 ─────────────────────────────
  airoff → ron   (측정 챔버 tank + 5L 위즈수조 *동시* 폭기)
       ※ 사전폭기: 측정 전 tank 1500s(25분) 고정 폭기로 평형 근처까지(미측정)
  ④ tank 평탄 측정 (30초 간격 반복, span4≤2mpH AND net8≤1mpH)
       ※ read 직전에만 폭기 off + 10초 정치(모터 노이즈 차단), 샘플 사이는 재폭기(ron)
       ※ 이 동안 5L 위즈수조가 co-aeration → ref 미리 평형 근처로

── 전이 (무대기: 홀딩 파킹으로 ref 측정 조기 시작) ──
  airoff → ton
  ⑤ m2b:68  측정 챔버 tank → 홀딩 *임시 파킹* (완전 배출 대신 빠른 비움)
  ⑥ m4f:60  참조수 5L → 측정 챔버 (동시폭기로 이미 평형 근처)

── [B] ref 평탄까지 ──────────────────────────────
  airoff → ron   (측정 챔버 ref + 5L 위즈수조 *동시* 폭기)
       ※ 사전폭기: 측정 전 ref 210s(3.5분) 고정 폭기(5L co-aeration이라 짧음)
  ⑦ ref 평탄 측정 (co-aeration이라 빨리 수렴, read 직전에만 폭기 off + 정치) → airoff
  ⑧ calkh    dKH 계산 + 출력 + 이력 저장
       └ calref 모드(--setref): calkh 대신 calref = ref dKH 역산·EEPROM 저장

── 정리 ─────────────────────────────────────────
  ton
  ⑨ m4b:70  참조수 측정 챔버 → 5L 위즈수조 회수 (긴 호스 +10)
  ⑩ m1b:82  파킹된 tank 홀딩 → 본수조 마무리 배출
  ⑪ m3f:60  KCl 재공급 (프로브 소크) → airoff
```

> 펌웨어는 측정 순서와 무관합니다. `ref`/`tank` 플래그가 독립 저장되고
> `calkh`/`calref`는 둘 다 갖춰진 뒤 계산하므로 tank 우선이어도 동작이 같습니다.
>
> **★규칙:** 모든 액체 이동(`mXf`/`mXb`) 직전에 `airoff`로 폭기를 끄고, 펌프 구동 전
> `ton`으로 PWM 제어기를 켭니다. 폭기(`ron`)는 *액체 정지 구간*(측정)에만.
>
> **★종료 상태:** V4는 측정 후 `airoff`(KCl 소크 상태)로 끝납니다 — 구 버전의
> "측정 사이 기포기 ON 유지(terminal ron)"는 **제거**되었습니다.
>
> 오류/비정상 종료 시 `_safe_cleanup`(에어 OFF → 측정 챔버 배출 `m2b:68`→`m1b:82`
> → KCl 소크 `m3f:60` 복원)이 돌고, KCl 소크 미검증이면 에러로 `0.0`을 기록합니다.

### 구현: PC측 스크립트 (bin/)

평탄(수렴) 판정(측정값 비교 후 반복 여부 결정)이 필요하므로 펌웨어 매크로가
아닌 PC측 파이썬 스크립트가 명령을 단계별로 전송합니다. (현재 펌웨어에는 `seq`
명령이 없습니다.)

| 스크립트 | 동작 |
|---|---|
| `bin/run_measure_and_sync.py` | **스케줄러 진입점(2026-07-05~)** — 측정 → 도저 조정(매회 오버라이드 확인, 매일 13시만 자동 권고) → 대시보드 동기화를 연쇄 실행 ([파이프라인](#측정-직후-대시보드-동기화-파이프라인)) |
| `bin/measure_kh_once.py` | **V4** — 1회 측정 후 종료 (래퍼가 호출, 수동 단독 실행도 가능) |
| `bin/doser_adjust.py` | 올포리프 도저 조정 — 권고 계산(자동 적용 꺼짐)·대시보드 수동/목표 설정 적용 ([사용설명서 §10](user-manual.md#10-도저-자동-조정-올포리프)) |
| `bin/sync_dkh_dat.py` | dkh.dat·평탄 이력·도저 이력을 저장소에 커밋/push (WSL, 래퍼가 호출) |
| `bin/dkh_server.py` | `GET /api/dkh`(포트 9999) 최신 측정값 JSON 서버 + 도저 수동 설정 5분 폴러 |
| `bin/test_aeration_plateau.py` | tank 단일 평형곡선 진단 (V4와 동일 평탄 기준, 종료 시 KCl 소크) |
| `bin/firmware_sim.py` | 소켓 가상 포트 펌웨어 시뮬레이터 (회귀 테스트용, WSL 전용) |
| `bin/test_measure_sim.py` | 통합 회귀 테스트 (23 시나리오/122 검증) — [상세](bt-reconnect-and-testing.md#3-시뮬레이터-회귀-검증-배포-전-필수) |
| `bin/bt_health.py` | (보조) HC-06 BT 링크 드롭률·RTT 모니터 |

**V4 (`measure_kh_once.py`) 주요 상수:**

| 상수 | 기본값 | 의미 |
|---|---|---|
| `FLAT_SPAN_N` | 4 | 흔들림(span) 판정 윈도우 — 최근 N개 |
| `FLAT_SPAN_MPH` | 2 | 최근 `FLAT_SPAN_N`개 정수 milli-pH의 (max−min) ≤ 2면 흔들림 통과 |
| `FLAT_NET_N` | 8 | 드리프트(net) 판정 룩백 — span보다 긴 창(★B1, 느린 단조 꼬리 조기 latch 차단) |
| `FLAT_NET_MPH` | 1 | 최근 `FLAT_NET_N`개 양끝차 ≤ 1이면 드리프트 통과(span·net 둘 다 통과해야 평형) |
| `FLAT_MIN_N_TANK` | 0 | **tank 전용** 최소 측정 횟수 게이트 — **2026-07-23 제거(20→0)**. 고정 사전폭기가 초기 불안정(전극 재평형·열 과도·혼합)을 *측정 전*에 흡수하므로 조기 false lock 근거 소멸. [이력] 20 은 2026-07-03 무딘 S커브 false lock 대응(7/4·7/17 검증). 새 곡선서 초기 조기잠금 재발 시 20 원복 |
| `MEAS_INTERVAL` | 30 | 측정 간 간격(초) — 이 구간엔 폭기 유지(read 직전에만 잠깐 off) |
| `PREAERATE_SECS` | tank 1500 / ref 210 | **측정 전 고정 사전폭기(초)** — tank 25분·ref 3.5분. 값=완주 이력(tank 51/ref 50런)의 '평탄 도달 중앙값 − net8 확인창' 중앙값. 시료를 평형 근처까지 올려 측정 구간을 단축(2026-07-23) |
| `SETTLE_SECS` | 10 | read 직전 `airoff` 후 정치(초) — 기포·전기 과도가 소산된 뒤 읽어 기포기 모터 노이즈 차단(2026-07-23) |
| `PHASE_MAX_SECS` | 5400 | phase별 최대 *측정* 시간(초)=90분(사전폭기 제외), 초과 시 마지막값+경고 |
| `MEAS_MAX` | 180 | phase별 최대 측정 횟수(백스톱)=5400/30 |
| `FAIL_MAX` | 5 | 연속 측정 파싱 실패 허용 → 초과 시 phase 실패 |
| `SEND_RETRY_MAX` | 3 | RF 순단 시 명령 재시도 횟수 |
| `KEEPALIVE_SECS` | 12 | 유휴 keepalive 간격(초) — HC-06 ~20초 유휴 드롭 예방 |
| `MEAS_READ_TIMEOUT` | 20 | 측정 1회 `[OK]` 대기 상한(초) |
| `LINK_PING_TIMEOUT` | 3 | `ensure_link`/`reconnect` 핑 응답 대기 상한(초) |

> RF 순단(블루투스) 대응 상수(`SEND_RETRY_MAX`·`KEEPALIVE_SECS`·`RECONNECT_TRIES` 등)와 그 동작은 [블루투스 통신 안정화 & 시뮬레이터 검증](bt-reconnect-and-testing.md)에서 자세히 다룹니다.

> 측정 구간은 **평형(평탄)까지 적응**하지만(구 `AIR_SECS`/`STABLE`/`CONV_EPS` 폐기), 그 앞에 **고정 사전폭기**(`PREAERATE_SECS`: tank 25분·ref 3.5분)가 붙어 시료를 미리 평형 근처로 올립니다(2026-07-23~). 측정 펌프초: tank 채움(본수조→홀딩) `m1f:70`·완전 배출(홀딩→본수조) `m1b:82`, 이송(홀딩↔측정챔버) `m2f:60`/`m2b:68`, 참조수(5L↔측정챔버) `m4f:60`/`m4b:70`(긴 호스라 역방향 +10), KCl `m3b:68`/`m3f:60`.

**`dkh.dat` 규약** (`YYYY-MM-DD HH ref_pH tank_pH ref_kh(8.448) tank_kh temp`):

- **날짜 컬럼**(2026-08-16~): 파싱·기록은 `bin/dkh_dat.py` 한 곳에서만 합니다. 저장소의 과거 행은 1회성 마이그레이션으로 날짜를 채웠고(커밋 `bc3e763`), 날짜가 없던 구형식(6필드)은 읽기만 관용 처리합니다. 이 컬럼 덕에 "최근 N일"이 회차 근사(하루 3회 가정)가 아니라 **날짜 그대로** 계산됩니다 — 날짜를 추측하던 코드(git blame 복원, 원격 series 정렬, 21행≈7일, 42회≈14일)는 전부 제거했습니다.

- **에러 표식 = 5값 전부 0** (측정 실패/타임아웃/KCl 소크 실패). **에러 래치**: 마지막 줄이 에러 표식이면 다음 실행은 측정 없이 에러 표식만 재기록 — 수동으로 마지막 에러 줄을 지우기 전까지(오류 무인 반복 방지).
- **평탄 미도달 = `tank_kh` 음수(−)** 표식 (값 크기는 유효, 서버가 부호로 인지). 전부-0 에러 표식과 구분되어 래치 안 걸림.
- 평탄 도달 여부·측정 횟수는 로그(`measure_kh.log`)와 결과 헤더(`평탄도달 : tank N회 O / ref N회 O`)에 남습니다.

### 1회 측정 실행법 (`measure_kh_once.py`)

1회만 측정하고 종료하는 스크립트입니다. Windows 작업 스케줄러가 정시(05:00/13:00/21:00)에 호출하지만, 수동 실행도 가능합니다.

**동작:** 준비 → **[A] tank 사전폭기(25분) + tank 평탄까지** → 전이 → **[B] ref 사전폭기(3.5분) + ref 평탄까지** → `calkh` → 정리 후 `airoff`(KCl 소크)로 종료. 고정 사전폭기(tank 25분 + ref 3.5분 ≈ 28.5분) 뒤 측정 구간이 평형까지 적응하므로 1회 소요는 가변이며 **대략 1시간 안팎**, 측정 phase 상한(각 `PHASE_MAX_SECS`=90분, 사전폭기 별도)까지 가면 더 길어질 수 있으나 worst-case도 약 3h45m로 스케줄러 상한(5h) 아래입니다.

**포트 지정:** 첫 번째 명령행 인자로 포트를 넘길 수 있고, 없으면 **단일 설정 파일 `bt_config.json`** 에서 측정기 포트를 읽습니다(아래 [BT 포트 설정](#bt-포트-설정--단일-설정-파일-bt_configjson) 참조). 포트가 바뀌어도 소스는 고치지 않습니다.

**모드:** 인자가 없으면 `calkh`(수조 dKH 측정 → `dkh.dat` 기록). `--setref <수조실측dKH>` 를 주면 `calref`(참조수 dKH 역산·EEPROM 저장, `dkh.dat` 기록 안 함) — 자세한 내용은 [사용설명서 §3.2](user-manual.md#32-자동-측정-pc-연동)를 참조하세요.

```bash
# 콘솔에서 출력을 보며 실행 (포트 = bt_config.json 의 measure)
python measure_kh_once.py

# 포트 직접 지정
python measure_kh_once.py COM7

# ref dKH 교정(역산) — 알려진 수조 dKH 기준
python measure_kh_once.py --setref 8.448

# 콘솔 없이 실행 (스케줄러 방식) — 출력은 C:\dkh\measure_kh.log 로 redirect
pythonw measure_kh_once.py

# WSL에서 Windows 파이썬으로 수동 실행 (cp949 인코딩 오류 회피용 -X utf8 필수)
/mnt/c/dkh/python313/python.exe -X utf8 'C:\dkh\work\measure_kh_once.py' 2>&1
```

**PowerShell에서 직접 실행** (정션 `C:\dkh` 경로 사용, `-X utf8` 필수):

```powershell
# 일반 측정 (calkh) — 출력을 콘솔에서 봄
& C:\dkh\python313\python.exe -X utf8 C:\dkh\work\measure_kh_once.py

# 포트 직접 지정
& C:\dkh\python313\python.exe -X utf8 C:\dkh\work\measure_kh_once.py COM7

# ref dKH 교정 (calref) — 수조 실측 8.448 dKH 기준으로 참조수 dKH 역산·저장
& C:\dkh\python313\python.exe -X utf8 C:\dkh\work\measure_kh_once.py --setref 8.448

# 콘솔 없이 (스케줄러와 동일) — 출력은 C:\dkh\measure_kh.log 로
& C:\dkh\python313\pythonw.exe -X utf8 C:\dkh\work\measure_kh_once.py
```

> - **COM 포트는 블루투스 페어링에 묶입니다.** 평소 유지되지만 재페어링·동글 교체·윈도우 업데이트 재열거로 번호가 바뀝니다. 그때는 소스가 아니라 **`bt_config.json` 한 곳만** 고칩니다([BT 포트 설정](#bt-포트-설정--단일-설정-파일-bt_configjson)).
> - 측정 포트는 스케줄러 작업과 공유하므로, **정시 측정(05/13/21시)이 진행 중일 때 수동 실행하면 시리얼 충돌**이 납니다.
> - `pythonw`는 `sys.stdout`이 `None`이라, 스크립트가 모든 출력을 `C:\dkh\measure_kh.log`로 보냅니다(1MB 초과 시 새로 시작).

### BT 포트 설정 — 단일 설정 파일 (`bt_config.json`)

블루투스 COM 포트는 **재페어링·USB 동글 교체·윈도우 업데이트 재열거**로 수시로 바뀝니다. 예전에는 그때마다 `measure_kh_once.py`·`doser_adjust.py`·`bt_health.py`의 `PORT` 상수와 스케줄러 작업 인자를 일일이 고쳤지만(누락·불일치 위험), **2026-07-21부터 설정 파일 한 곳만 고치면 모두 반영**됩니다.

**설정 파일:** `C:\dkh\bt_config.json` (실전 위치 — 코드 배포 `cp bin→work`로 안 덮이도록 일부러 `work\` 바깥, 로그들과 같은 `C:\dkh\`에 둠). 저장소 `bin/bt_config.json`은 기준값 겸 시뮬레이터(WSL)용 사본.

```json
{
  "devices": {
    "measure": { "port": "COM14", "mac": "98DA600FC57A", "desc": "측정기 HC-06" },
    "doser":   { "port": "COM12", "mac": "98DA60056895", "desc": "도저 ca_reactor" }
  }
}
```

**포트 바꾸는 법:** `C:\dkh\bt_config.json`의 해당 `port` 값만 새 COM 번호로 수정하면 끝(재부팅·재등록 불필요, 다음 실행부터 반영). `mac`은 참고·확인용입니다.

**새 COM 번호 확인:**
```powershell
Get-PnpDevice -Class Ports -PresentOnly | ForEach-Object { "$($_.FriendlyName)  ||  $($_.InstanceId)" }
# InstanceId 끝의 MAC(예: ...&0&98DA600FC57A_...)으로 어느 기기인지 식별
```

**공용 로더(`bt_config.py`)** 가 `환경변수 AQUAWIZ_BT_CONFIG → C:\dkh\bt_config.json → 모듈폴더/bt_config.json → 내장 폴백` 순으로 찾습니다. 설정 파일이 없어도 마지막으로 알려진 포트(내장 폴백)로 동작해 측정이 죽지 않습니다. 진단:
```powershell
& C:\dkh\python313\python.exe -X utf8 -c "import bt_config; print(bt_config.config_path(), bt_config.all_ports())"
```

**적용 대상:** `measure_kh_once.py`(measure), `bt_health.py`(measure), `doser_adjust.py`(doser). `set_time.py`는 인자로 `measure`/`doser` 이름을 받으면 설정에서 포트를 해석하므로(예: `set_time.py doser`), **스케줄러 작업 인자를 장치 이름으로 두면 이후 포트가 바뀌어도 작업 재정의(관리자 권한)가 영영 불필요**합니다.

> ⚠️ **CSR USB 동글 사용 시:** 동글이 인식되려면 PC 내장 BT 라디오(인텔 8265 등)를 장치 관리자에서 "사용 안 함" 처리해야 합니다(Windows는 BT 라디오를 한 번에 하나만 활성화 — 안 그러면 동글이 "문제 코드 31"). 이때 내장 BT에 붙어 있던 BT 마우스 등은 동글로 재페어링하거나 USB로 바꿔야 합니다.

### Windows 작업 스케줄러 등록 (정시 자동 측정)

래퍼 `run_measure_and_sync.py`(측정→도저 조정→동기화 연쇄)를 **매일 05:00 / 13:00 / 21:00**(05시부터 8시간 간격, 하루 3회) 자동 실행하는 예입니다. 한 개의 반복 패턴(Repetition) 대신 **고정 시각 Daily 트리거 3개**를 씁니다 — 매일 재무장되어 재부팅 후에도 스케줄이 깨지지 않고, 꺼져 있던 시간대의 측정은 보충하지 않습니다(의도된 동작). (2026-07-05까지는 `measure_kh_once.py`를 직접 실행하고 WSL cron이 별도로 동기화했으나, 측정이 길어지면 부분 데이터가 올라가는 문제로 **측정 완료 직후 동기화** 방식으로 전환했습니다.)

**관리자 PowerShell**에서 실행합니다(한글 경로 문제를 피하기 위해 ASCII 정션 `C:\dkh` 경로 사용):

```powershell
# 1) 하루 3회 고정 시각 트리거 (05시 + 8h 간격)
$triggers = @(
    New-ScheduledTaskTrigger -Daily -At 05:00
    New-ScheduledTaskTrigger -Daily -At 13:00
    New-ScheduledTaskTrigger -Daily -At 21:00
)

# 2) 콘솔 없는 pythonw 로 래퍼(측정→도저 조정→동기화) 실행
$action = New-ScheduledTaskAction `
    -Execute 'C:\dkh\python313\pythonw.exe' `
    -Argument 'C:\dkh\work\run_measure_and_sync.py'

# 3) 설정: 배터리·유휴로 중지 금지, 1회 상한 5h(측정 자체 최대 ~4h + 조정·동기화 여유), 중복 실행 시 새 인스턴스 무시
$settings = New-ScheduledTaskSettingsSet `
    -AllowStartIfOnBatteries -DontStopIfGoingOnBatteries `
    -ExecutionTimeLimit (New-TimeSpan -Hours 5) `
    -MultipleInstances IgnoreNew
$settings.IdleSettings.StopOnIdleEnd = $false

# 4) 로그인한 대화형 세션의 사용자 토큰으로 실행 (COM 포트는 사용자 세션에 바인딩됨)
$principal = New-ScheduledTaskPrincipal -UserId $env:USERNAME -LogonType Interactive

Register-ScheduledTask -TaskName 'Measure KH' -TaskPath '\tsyi\' `
    -Trigger $triggers -Action $action -Settings $settings -Principal $principal -Force
```

설정값의 이유:

| 설정 | 값 | 이유 |
|---|----|---|
| `AllowStartIfOnBatteries` / `DontStopIfGoingOnBatteries` | 켬 | 노트북에서 기본값(배터리 시 중지)이 데몬·측정을 로그 없이 강제 종료하는 문제 회피 |
| `IdleSettings.StopOnIdleEnd` | `$false` | 유휴 종료 시 작업이 중단되지 않도록 |
| `ExecutionTimeLimit` | 5h | V4 1회 측정은 사전폭기(≈28.5분) + 평형 적응 측정이라 대개 **1시간 안팎**이지만, tank·ref 두 phase가 모두 측정 상한(각 `PHASE_MAX_SECS`=90분)에 걸리면 사전폭기 포함 worst-case ~3h45m + 도저 조정·동기화·이송·정리 여유가 필요. 정당한 장시간 측정을 죽이지 않도록 5h(멈춘 프로세스는 시리얼 타임아웃·`write_timeout`·`FAIL_MAX`로 스크립트가 자체 종료) |
| `MultipleInstances` | `IgnoreNew` | 직전 측정이 진행 중이면 다음 정시 트리거는 스킵 |
| `LogonType` | `Interactive` | COM(블루투스) 포트가 사용자 세션에 바인딩되어, 로그인된 대화형 세션에서만 접근 가능 |

> **로그인 세션 필요:** 로그아웃하면 세션·토큰이 파괴되어 작업이 죽습니다. 자리를 비울 땐 로그아웃 대신 **잠금(Win+L)** 을 쓰면 세션이 유지되어 계속 동작합니다(절전·디스플레이 OFF는 무방). 자동 복귀가 필요하면 자동 로그인을 권장합니다.
>
> 복잡한 PowerShell은 bat에 인라인으로 쓰지 말고 `.ps1`로 분리한 뒤 `register_measure_kh.bat`에서 `powershell -ExecutionPolicy Bypass -File "%~dp0register_measure_kh.ps1"` 한 줄로 호출합니다(한글 경로 + `^` 줄연속 조합 인코딩 오류 회피).

### 운용 메모

- 참조수 5L 증발 농축(1% ≈ +0.08 dKH 상당) → 주기적 RODI 수위 보충 또는 `calref`
- 3M KCl 제조: RODI 1L당 KCl 224g (≈22% w/v). 포화(≈4.2M@25°C) 대비 여유가
  있어 저온에서도 석출 없음
- 수동·단발 테스트는 펌웨어 명령(`ref`/`tank`/`calkh`, 모터·에어)으로 직접 가능하나
  (user-manual.md 참조) 평탄(수렴) 판정은 PC측 스크립트만 지원
- 측정 중 방 CO₂ **드리프트**(저녁 환기 변동 등)는 개방 셋업에서 tank·ref를 다른 평형에서
  latch시켜 오차를 만들 수 있었으나, **밀폐 공통 헤드스페이스가 이 원인을 구조적으로 제거**합니다
  (외부 공기 차단 → 헤드스페이스 pCO₂ 고정 + 평형 즉시 도달로 측정 시간차 붕괴). 상세 검증은 [측정 대장](measurement-ledger.md) 참조

### 측정 직후 대시보드 동기화 파이프라인

측정 결과는 사람 개입 없이 [GitHub Pages 대시보드](https://taeseokyi.github.io/reefwiz/)까지 자동으로 흐릅니다 (2026-07-05 전환 — 이전의 WSL cron 방식은 측정이 길어지면 부분 데이터가 올라가는 문제가 있어 폐지):

```
Windows 스케줄러 (05/13/21시)
  └ run_measure_and_sync.py (래퍼, C:\dkh\work)
      ① measure_kh_once.py  — V4 측정 → dkh.dat 기록
      ② doser_adjust.py     — 대시보드 수동 도징 설정 확인·적용(매회)
      │                       + 자동 조정 권고 계산(매일 13시 회차만)
      ③ wsl.exe → sync_dkh_dat.py — dkh.dat·평탄 이력·도저 이력 커밋/push
          └ GitHub Actions (make_dkh_json.py) → Pages 갱신 (수 분 내)
```

- 동기화는 측정이 완전히 끝난 뒤에만 시작되고, 실패해도 측정 결과(dkh.dat·로그)에는 영향이 없습니다 — push 실패분은 다음 회차의 push가 복구합니다. rebase는 `--autostash`라 작업 중 미커밋 변경이 있어도 동기화가 진행됩니다.
- 도저 조정 실패·타임아웃도 동기화를 막지 않습니다. 조정 개념·안전 한계는 [사용설명서 §10](user-manual.md#10-도저-자동-조정-올포리프) 참조.
- 별도로 `dkh_server.py`(작업 "DKH Server")가 `GET /api/dkh`(포트 9999)로 최신 측정값 JSON을 제공하고, 5분 간격 폴러로 대시보드의 도저 수동 설정을 측정 대기 없이 적용합니다.
- 래퍼·조정 스크립트 원본은 저장소 `bin/`, 배포본은 `C:\dkh\work\` — **수정 시 재복사 필수**.

### 블루투스 통신 안정화 & 시뮬레이터 검증

측정은 HC-06 블루투스 SPP(COM9)로 통신하는데, 이 RF 링크가 간헐적으로 끊긴다(주로 **명령을 보내려는 순간 이미 끊겨 있음**). 이에 대응해 `measure_kh_once.py`의 `send()`는 다음을 보장한다.

1. **송신 전 연결 확인**(`ensure_link` = `status` 핑) — 모든 명령은 보내기 전 링크 생존을 확인
2. 끊겼으면 **재연결**(`reconnect` = 포트 `close→open` + 펌웨어 응답 확인)
3. 보낸 뒤 연결 문제(예외·응답 미수신)면 **재연결 후 재시도**(`SEND_RETRY_MAX`회)
4. **모터는 재시도 시 먼저 정지(`mNs`) 후 재송신** — 펌프 중복 구동 방지
5. (예방) 유휴 구간 **keepalive** — 12초마다 빈 줄로 ~20초 유휴 드롭 차단
6. **장기 링크 사망 보강(2026-07-03)** — `write_timeout=5`(write 무한 블로킹 좀비 방지), 평탄 phase 중 링크 사망 시 phase 마감까지 60초 간격 끈질긴 재접속(폭기 유지=평형 보존), calkh 불능 시 시작 캐시 refKH로 호스트가 dKH 계산·음수 기록(호스트 구제)

호스트측으로는 Wi-Fi/BT 네트워크 장치 비활성화·USB 선택적 절전 OFF로 2.4GHz 간섭·포트 절전을 줄인다.

**회귀 검증(배포 전 필수):** 소켓 가상 펌웨어 시뮬레이터로 정상·예외 상황을 검증한다.

```bash
cd bin && python3 test_measure_sim.py     # WSL, 23 시나리오/122 검증 — 전부 PASS여야 배포
```

> 증상·호스트 조치·4계층 동작·상수·시뮬레이터/테스트 구성(시나리오 표)·배포 안전성은
> **[블루투스 통신 안정화 (RF 순단 대응) 및 시뮬레이터 회귀 검증](bt-reconnect-and-testing.md)** 에 상세히 정리되어 있다.

## 온도 환경

위즈 탱크(5L) 안에 모든 비이커(200ml)가 담겨 있으므로:

- 참조수, 수조수 샘플, 3M KCl이 모두 동일 온도로 유지됨
- DS18B20이 위즈 탱크 수온을 측정하여 Nernst 온도 보상에 사용
- pH 전극의 온도 보상이 정확해짐

## 측정 정확도

### Nernst 온도 보정

pH 전극의 기울기는 온도에 따라 변합니다 (Nernst 방정식: slope = 0.19842 × T(K) mV/pH). 보정 온도를 EEPROM에 저장하여 보정 시와 측정 시 온도가 달라도 정확하게 보상합니다.

```
pH_corrected = 7.0 + (pH_raw − 7.0) × (273.15 + T_cal) / (273.15 + T_meas)
```

보정 온도 저장 후 **15°C~35°C 전 범위에서 Nernst 보정 오차 0%**입니다.

### 오차 요인 분석 (dKH 8.5 기준)

| 요인 | pH 오차 | dKH 오차 | 비고 |
|---|---|---|---|
| ADS1115 ±1 LSB | ±0.0007 pH | ±0.010 | 16비트 ADC |
| 64회 오버샘플링 | ÷8 | ±0.001 | √64 = 8배 개선 |
| Nernst 보정 | 0 | 0 | 보정 온도 EEPROM 저장 |
| DS18B20 ±0.5°C | ±0.0017 pH | ±0.023 | 온도 센서 정밀도 |
| **pH 프로브 반복성** | **±0.005 pH** | **±0.070** | **지배적 오차 요인** |
| **전체 (RSS)** | | **±0.073 dKH (±1.2%)** | |

### 시스템 성능 요약

```
측정 분해능:    ±0.001 dKH (소수점 3자리)
시스템 정확도:  ±0.07 dKH (±1.2%)
유효 자릿수:    소수점 이하 2자리
```

> 정확도의 97%는 pH 프로브(유리전극) 자체의 반복성에 의해 결정됩니다. ADC, Nernst 보정, 펌웨어 계산 로직은 프로브 성능을 충분히 살릴 수 있는 수준입니다.

### 실측 안정성 (KCL 용액, 5회 연속)

```
전압 편차: ±0.061 mV
pH 편차:   ±0.0005 pH
온도:      28.6°C 일정
```

> ADS1115 16비트 분해능의 이론적 한계에 근접하는 안정성입니다.

### 진단: 프로브 vs 셋업 분리 (널 테스트)

측정 시 참조수 pH와 수조수 pH 사이에 ΔpH 오프셋이 남을 수 있습니다(두 물이 동일 해수라면 이상적으로 ΔpH = 0). 이 오프셋의 원인이 **프로브·경로의 측정 아티팩트**인지, **두 물의 실제 화학 차이(CO2 탈기 비대칭)**인지 가르는 절차입니다.

**왜 재보정이 답이 아닌가:** dKH는 차동식(`KH_tank = KH_ref × 10^(−ΔpH)`)이라, pH 보정의 offset 오차는 참조·수조 양쪽에 똑같이 실려 ΔpH에서 상쇄되고, slope 오차도 작은 ΔpH(보통 0.02~0.07)에 비례하므로 영향이 미미합니다. 따라서 오프셋을 재보정(`calph`)으로 잡으려 하면 노이즈만 늘 뿐이며, 먼저 원인을 분리해야 합니다. (재보정은 절대 pH 동작점을 ADC 선형구간 안으로 유지하는 **예방·점검**용입니다.)

**절차:** **동일 해수**를 참조 경로와 수조 경로 양쪽에 넣고(진짜 ΔKH=0) V4로 측정합니다. V4는 양쪽을 (사전폭기 후 read 직전에만 폭기를 끄며) 진짜 평형까지 끌고 가므로, 남는 ΔpH가 프로브·경로 아티팩트인지 판별하기 좋습니다.

| 결과 | 해석 | 조치 |
|---|---|---|
| ΔpH ≈ 0 | 프로브·경로 정상, 차동이 방 CO₂를 잘 상쇄 | 그대로 운용 |
| ΔpH = 작은 상수 (방 CO₂ 무관, 재현) | 구조 baseline 후보 (경로 비대칭 등) | **영점보정은 독립 재현 확인 후** — 동일 해수 새 널테스트로 일정 vs 우연 판정 ([측정 대장](measurement-ledger.md)) |
| ΔpH가 방 CO₂ 따라 변동 | 폭기/평형 비대칭(미완) 또는 외기 유입 | **밀폐 공통 헤드스페이스 확인**(분리 밀폐·누설 점검), 평탄 도달 확인(`평탄도달 O`) |

> **현황(2026-06):** 개방 셋업(200mL 개방 챔버 tank + 5L 반밀폐 ref) 널테스트에서 V4가 방 CO₂ 의존성을 제거(ΔpH −0.042/−0.043 동일)했으나 baseline은 상수가 아니었고(13:00 −0.026, +0.29 dKH = 증발 confound 의심), 무보정 원시오차도 −0.78로 컸습니다. **2026-06-19 밀폐 공통 헤드스페이스 적용 후 첫 새벽 측정에서 ΔpH가 −0.008로 붕괴**(새벽 오차 제거)하고 원시오차도 −0.165로 줄어 목표 정확도 안에 들어왔습니다 — 밀폐가 새벽 CO₂와 증발 두 잔여 오차원을 동시에 덮은 것으로 보입니다. 다만 단일 점이므로 13:00 밀폐 측정(증발 흩어짐 판정)·시계열 누적까지는 **영점보정 확정을 보류**합니다. 상세는 [측정 대장](measurement-ledger.md).

**프로브 건강 계기:** 별도 장비 없이 `measure_kh.log`의 **평탄 도달까지 측정 횟수**(`tank N회 / ref N회`)로 전극·평형 상태를 모니터링합니다. 같은 조건에서 횟수가 점차 늘면 응답 둔화(노화) 또는 접합부(KCl junction) 오염 신호이며, 이때 묽은 HCl 접합 세척을 검토합니다. 접합전위 1 mV 변동 ≈ 0.017 pH ≈ 0.3 dKH이므로 무시할 수 없습니다. (단, 평탄 횟수는 폭기 평형시간·시작 격차에도 좌우되므로 추세로 해석.)

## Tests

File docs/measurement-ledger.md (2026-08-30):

# KH 측정 대장 (코드 상태 · 환경 · 결과)

> 관련 문서: [프로젝트 개요 (README)](../README.md) | [자동화 환경 구성](system-setup.md) | [사용 설명서](user-manual.md) | [준비물 목록](parts-list.md)

> **이 문서의 의의:** 측정 정확도의 신뢰성을 떠받치는 1차 기록이다. 코드 버전(V0~V4)별 실측, 환경(방 CO₂) 통제, 차동 측정이 방 CO₂ 의존성을 제거함을 보인 ΔpH 검증, 그 해석을 뒷받침한 학술 문헌까지 — 많은 시행착오의 결과를 시각순으로 남긴다.

*실시간 그래프(하루 3회 측정 자동 반영)는 [대시보드](https://taeseokyi.github.io/reefwiz/)에서 확인. 전체 이력 원본은 [`data/dkh.dat`](../data/dkh.dat).*

ΔpH/dKH 검증을 계속하려면 "각 측정이 어떤 코드·환경에서 나왔는가"를 정확히 알아야 한다.
git 커밋만으로는 부족하다 — **6/16 13:00 변경(STABLE·EPS)과 v2 재작성은 커밋되지 않고 작업트리에서만
돌았다.** 그래서 이 대장에 측정 시각별로 직접 기록한다.

**기록 원칙:** 새 측정이 끝날 때마다 아래 표에 한 줄 추가. 값은 `measure_kh.log`(실제 실행 진실)와
`dkh.dat`에서 가져온다. 코드를 바꾸면 ① 새 "코드 버전" 항목을 정의하고 ② 가능하면 **커밋해 SHA를 남긴다**
(미커밋이면 표에 `(작업트리)`로 표기). 환경(방 CO₂)은 직접 로그가 없으므로 **절대 pH를 대리지표**로 쓴다
(절대 pH 낮음 = 방 CO₂ 높음). dKH 계산: `tank_dKH = 8.448 × 10^(−(ref_pH−tank_pH))`, ΔpH는 `tank_pH − ref_pH`.

dkh.dat 컬럼: `YYYY-MM-DD HH ref_pH tank_pH ref_kh(앵커 8.448) tank_kh temp`
- **날짜 컬럼**(2026-08-16 도입): 그 전까지는 시각(HH)만 있어서 소비자들이 "최근 N일"을 하루 3회 가정의 **회차 근사**로 세거나 git 커밋 시각·원격 정렬로 날짜를 복원해야 했습니다. 과거 273행은 1회성 마이그레이션 스크립트로 채워 넣었습니다(평탄 아카이브 `run_started`와 교차검증 127/128 일치 — 스크립트는 소임을 다해 제거, 커밋 `bc3e763` 에 남아 있습니다). 그 뒤 날짜 복원·회차 근사 코드는 전부 걷어냈고, 날짜 없는 구형식은 읽기만 관용 처리합니다(`bin/dkh_dat.py`).
- **에러 표식**: 5개 값 전부 `0.000…0.0` = 측정 실패/타임아웃/KCl 소크 실패. **에러 래치**(V4): 마지막 줄이 에러 표식이면 다음 실행은 측정 없이 에러 표식만 재기록 — *수동으로 마지막 에러 줄 제거* 전까지(오류 무인 반복측정 방지).
- **평탄 미도달 표식**(V4): `tank_kh`가 **음수(−)** = 정상 측정이나 평형 미도달(값 크기 유효, 서버가 부호로 인지). 에러 표식(전부 0)과 구분되어 래치 안 걸림.

---

## ★★★ 최종 결론 (2026-06-21) — 목표 정확도 달성, 계측 offset −0.06

며칠간의 "널테스트 오차가 계측기 결함인가, 물 문제인가" 모호함이 **완전 널테스트**로 종결되었다.

**핵심 결과 (완전 널, 6/21 19:00):** 위즈(5L) 해수를 떠서 tank 외부 챔버 100mL에도 넣어 **ref·tank 양쪽을 같은 물**로 만들었다(물 차이 = 구성상 0). 양쪽 모두 진짜 평탄 도달(tank 21회·ref 18회 O), 온도 27.4℃ 안정:

| 측정 | ΔpH | dKH | 무보정 오차 (vs 8.448) |
|---|-----|-----|---|
| **완전 널 (양쪽 같은 물)** | **−0.003** | **8.387** | **−0.061** |

**−0.92 절대오차의 정체 완전 규명:**
- **−0.86 dKH = 옛 200mL tank 시료 물의 알칼리니티 손실** (6일 개방+반복 폭기로 CaCO₃ 석출/생물막 → 알칼리니티 감소). *증발은 KH를 올리지만(밀폐가 차단), 폭기가 CaCO₃ 과포화를 키워 석출시키는 손실이 더 컸다.*
- **−0.06 dKH = 계측기 순수 시스템 offset** (물 차이 0에서 측정 → ΔpH −3mpH = 분해능/전극 미세 비대칭 수준).

**입증 경로 (부분 널 → 완전 널):**
```
옛 tank 물 (6/20~21):      ΔpH −0.05   dKH 7.4~7.6   오차 −0.9   ← 옛 시료 물 degrade
신선 tank vs 옛 5L (13:00): ΔpH −0.008  dKH 8.298     오차 −0.15  ← tank만 신선으로 교체
완전 널, 양쪽 같은 물(19:00): ΔpH −0.003  dKH 8.387     오차 −0.06  ← 물 차이 0 = 순수 offset
```

**목표 판정 ([README](../README.md) 사양 ±0.07, 사용자 희망 ±0.25 / 허용 ±0.5):**
- 정밀도(흩어짐): SD ±0.08 dKH → 합격
- 계측 offset: −0.06 dKH → ±0.25의 1/4, **영점보정 불요**(보정 가치 없음)
- ⟹ **희망 ±0.25 dKH 달성 확정.** 실제 리프수조의 정상 물이면 무보정 ±0.1 안.

**이를 가능케 한 3대 조건:**
1. **밀폐 공통 헤드스페이스** — ref·tank 같은 pCO₂ 공유(방 CO₂ 공통모드 상쇄) + 증발 차단.
2. **완전평형 측정** — 4시간 상한 + B1 평탄 게이트(span4 AND net8≤1)로 양쪽이 *진짜* 대기평형 천장까지. ⟹ 부피 비대칭(100mL vs 5L)도 완전평형에선 상쇄됨을 실측 확인.
3. **차동식** `KH_tank = 8.448 × 10^(ΔpH)` — 절대 pCO₂가 공통모드로 소거.

상세 시각순 기록은 아래 측정 기록표, 손실 메커니즘은 본 문서 "★석출(CaCO₃) 가설" 섹션 참조.

---

## ★★★ 며칠간 동일시료 완전 널 캠페인 통계 (2026-06-23 05:00 ~ 06-27 05:00, n=13)

6/22 22:00 시료 신선화(대용량 마개 외부챔버 + 해수 보충) 이후, **장치·시료 무변경으로 4일간 1일 3회(05/13/21시) 동일 시료 완전 널**을 연속 측정했다. 참값 = ref 앵커 **8.448 dKH**(같은 물 → 차동식상 출력이 앵커와 같아야 함, 편차 = 순수 계측 오차).

**통계 요약 (n=13, 출력 dKH):**

| 지표 | 값 | 판정 |
|---|-----|---|
| 평균 출력 | **8.318 dKH** | (참값 8.448) |
| **편향 (bias)** | **−0.130 dKH** | \|편향\| ≤ 0.25 → 희망목표 충족 |
| 편향 95% CI | **[−0.167, −0.093]** | **0 미포함 → 편향 실재(통계적 유의)** |
| **정밀도 σ** | **0.061 dKH** | 희망 ±0.25의 1/4 → 우수 |
| RMSE (총오차) | **0.142 dKH** | ±0.25 안 |
| 평균 95% CI | 8.318 ± 0.037 | — |
| **단발 1회 95% 예측구간** | −0.130 ± 0.120 = **[−0.25, −0.01]** | 아무 1회나 95% 확률로 참값 ±0.25 안 |
| ΔpH(tank−ref) 평균 | **−6.7 mpH** (SD 3.1) | ref>tank 계통 = 액간전위/전극 비대칭 |

**핵심 결론:**
1. **−0.13 dKH의 계통 편향이 실재한다** (95% CI가 0을 배제). 6/21 완전 널의 −0.06보다 약 2배 큰 값으로, **"−0.06·영점보정 영구 불요"(6/21 결론)는 이 캠페인으로 갱신됨** — 잔여 baseline이 더 크다.
2. **★온도·KCl은 원인이 아님 (사용자 결론).** 편향 vs 수온 상관계수 **r = −0.10**(≈0, 25.1~27.6℃ 범위 내 무상관)으로 온도 배제가 데이터로도 정합. KCl도 배제됨. ⟹ **남은 유력 원인 = 액간전위/기준전극 비대칭**(ΔpH가 일관되게 tank<ref −6.7mpH인 계통 offset, [project-kh-offset-aeration-test](notes/project-kh-offset-aeration-test.md)의 정적 baseline 항).
3. **그래도 목표는 충족**: 편향 −0.13 + 정밀도 σ 0.06 → RMSE 0.14, 단발 예측구간도 ±0.25 안. 희망 ±0.25 / 허용 ±0.5 모두 합격(영점보정으로 −0.13 제거하면 ±0.06까지 가능하나 운영상 불필요).

**신뢰수준 / 필요 표본수 (널 테스트라 σ 기지):**
- 편향 추정 95% CI = ±1.96σ/√n. **±0.25 보장 n≥1, ±0.1 보장 n≥2, ±0.05 보장 n≥6.**
- 현재 n=13으로 편향은 이미 ±0.037(95%)까지 좁혀짐 → **신뢰수준 확보 목적의 추가 측정 불필요.** 성능은 통계적으로 충분히 특성화됨.
- 정밀도를 더 줄이는 건 횟수가 아니라 물리(전극 드리프트·액간전위) 문제 = 단발 ±0.1 바닥([project-accuracy-target](notes/project-accuracy-target.md) 6/26).

---

## ★★★ calref 실전 재보정 + 올포리프(All-For-Reef) 투입 + 신뢰도 평가 (2026-06-27 21:00 ~ 07-01 13:00)

며칠간 이어진 완전 널 캠페인(위 섹션, n=13, ~6/27 13:00 종료) 직후, 그날 저녁 21:00에 **최초로 라이브 본수조를 대상으로 `calref` 실전 재보정**을 수행 → 이후 "정식 측정"(널테스트가 아닌 실제 수조 dKH 추적) 시작.

**calref 이벤트 (2026-06-27 21:00):** 핸드테스트(사용자 실측) 수조 dKH **7.000** → `--setref 7.000` → 펌웨어 `calref`가 ref dKH 역산·EEPROM 저장: **8.448 → 8.830**. `dkh.dat`: `21 7.886 7.786 8.830 7.000 29.6`. 이 시점부터 `ref_kh` 컬럼이 8.830으로 전환.

**타임라인 (05/13/21시 3회/일 스케줄, 12회 전부 정상측정·에러/미평탄 0건 — dkh.dat 최종 줄이 measure_kh.log의 2026-07-01 13:00 항목과 일치해 8시간 간격 역산으로 날짜 복원):**

| 시각 | 수조 dKH | 온도(℃) | 비고 |
|---|---|---|---|
| 6/27(토) 21:00 | **7.000** | 29.6 | calref 앵커(핸드테스트 실측) |
| 6/28(일) 05:00 | 6.957 | 29.1 | |
| 6/28(일) 13:00 | **6.935** | 29.6 | 최저점 |
| 6/28(일) 21:00 | 6.993 | 29.7 | **올포리프 55mL 투입**(사용자 확인 — 타임라인 정확히 일치) |
| 6/29(월) 05:00 | 7.066 | 28.9 | 회복 시작 |
| 6/29(월) 13:00 | 7.174 | 29.4 | |
| 6/29(월) 21:00 | 7.254 | 29.7 | |
| 6/30(화) 05:00 | 7.281 | 29.3 | 플래토 진입 |
| 6/30(화) 13:00 | 7.281 | 29.6 | |
| 6/30(화) 21:00 | 7.287 | 29.7 | |
| 7/1(수) 05:00 | 7.267 | 29.4 | |
| 7/1(수) 13:00 | 7.282 | 29.9 | 최신(이 기록 시점) |

- **투입 효과:** 최저점 6.935 → 플래토 7.28대까지 **+0.345 dKH**, 상승은 즉발 스파이크가 아니라 ~1.5일에 걸친 완만한 곡선(올포리프 특유의 서방형 반응과 정합).
- **안정성:** 6/30 05:00부터 5회 연속 7.267~7.287 — 하락 저지+안정화 성공.

**정밀도 평가:** 6/30 05:00~7/1 13:00 플래토 5점 SD ≈ **0.008 dKH**(범위 0.020) — 며칠간의 널캠페인이 확립한 단발 잡음바닥 σ0.061([project-accuracy-target](notes/project-accuracy-target.md))보다 훨씬 타이트함. n=5라 새 정밀도로 확정 짓기엔 이르나(σ0.061 자체가 여러 날 표본이라 순수 측정잡음 외 환경드리프트까지 포함해 부풀려졌을 가능성 + 지금은 진짜 평형이라 신호도 안정), 최소 σ0.06 수준은 확실히 지키고 있다는 추가 증거. ⟹ **추세·변화량(하락→투입→회복→평탄 곡선)은 노이즈에 매몰되지 않는 신뢰 가능한 신호.**

**정확도(절대값) 평가 — 한계는 계측기가 아니라 기준측정법 쪽:** 이 시점부터 절대 정확도는 6/27 21:00 calref 앵커(핸드테스트 7.000) 단 1점에 의존. calref가 그 순간의 ΔpH를 새 ref_kh에 흡수시키는 구조라, 며칠간의 캠페인이 찾은 계통편향(−0.13 dKH, 액간전위/전극비대칭)이 상당 부분 상쇄됐을 것으로 추정되나 검증되진 않음(그 편향이 ΔpH 도메인의 진짜 상수라는 가정에 의존). **★사용자 확인(2026-07-01): 시중 리프 KH 테스트킷/체커 자체가 7.28 같은 값을 확정할 만큼 정밀하지 않음.** 추가 핸드테스트로 앵커를 교차검증해도 "대략 7~7.5대"라는 정보 이상은 못 얻음 — **한계가 AquaWiz 쪽이 아니라 가용한 기준측정법(ground truth) 해상도 쪽에 있음**(AquaWiz 재현성 σ0.06~플래토 0.008이 오히려 이 기준측정법들보다 더 좋음). ⟹ 절대값의 마지막 자리(7.28 vs 7.2 vs 7.3)는 이 시스템도 어떤 핸드테스트도 답할 수 없는 질문 — 목표(±0.5 허용/±0.25 희망)가 애초에 이 현실적 해상도 한계에 맞춰 설정된 것([project-accuracy-target](notes/project-accuracy-target.md), 상용 AquaWiz "0.5 이하=excellent·추세용" 기준과 일치, [reference-aquawiz-overseas-cases](notes/reference-aquawiz-overseas-cases.md)). 남은 검증 근거는 외부 교차검증이 아니라 **내부 일관성**(위 타임라인의 매끈한 하락→투입→회복→평탄 곡선 자체) — 순수 노이즈였다면 이런 물리적으로 그럴듯한 곡선이 나오기 어려움.

**밀폐 챔버 온도 정정:** 이 구간 온도 28.9~29.9℃는 dkh.dat 온도컬럼이 **완전 밀폐형 측정챔버 내부에서 평형된 수온**이기 때문(리프위즈 박스 자체가 완전밀폐라 승온, 사용자 확인). 메인 리프탱크의 실제 수온 대리값이 아니며, ref·tank가 같은 온도를 공유해 dKH 계산(차동식)엔 무관함. [project-dkh-temp-column-is-sealed-box](notes/project-dkh-temp-column-is-sealed-box.md)

---

## ★★ 운영 사건 로그 (2026-07-02 ~ 07-06) — BT 장기 사망 보강 · false lock 수정 · 자동화 확장 · 에어컨 계절 전환

정식 측정(3회/일) 지속 중 발생한 사건·수정·환경 변화의 시각순 기록.

- **7/2(목) 21시 — BT 장기 사망 사고(도저 설치 작업 중 끊김):** keepalive `write()`가 반열림 COM에서 무한 블로킹(당시 `write_timeout` 미설정) → 좀비 → 스케줄러 5h 상한에 강제 종료(에러 행·정리 미실행). 21시는 결측 — tank 7.816(평탄)·ref 7.905(2회뿐=미평탄)로 **수동 계산 7.194를 기록**(dkh.dat에서 실측과 구분 안 되므로 추세 해석 시 주의). 챔버 참조수는 당일 수동 정리로 KCl 오염 없음.
- **7/3(금) — 장기 링크 사망 보강 4종 배포:** `write_timeout=5`·평탄 중 링크 사망 시 phase 마감까지 60초 간격 끈질긴 재접속·호스트 구제(시작 캐시 refKH로 음수 기록=0.0 래치 회피)·ps1 상한 5h 정합. 시뮬 시나리오 [18][19] 추가. 13시 첫 실전 런 정상(7.236). 상세: [블루투스 재연결 §2.5](bt-reconnect-and-testing.md)
- **7/3(금) 05:00 — V4 false lock 발견·수정:** 7.509 기록(참값 ~7.24) — 저진폭 날 초기 lag 구간(무딘 S커브의 평탄한 초입)을 평형으로 오인한 조기 잠금. 수정 = `FLAT_MIN_N_TANK=20`(tank 전용 최소 20회=10분, ref는 co-aeration이라 미적용). 시뮬 [20]으로 재현·차단 검증(총 20 시나리오/97 검증).
- **7/4(토) 05:00 — MIN_N 첫 실전 검증 성공:** 초기 언덕 재현(샘플 1~7이 7.844로 평탄해 보임) → 게이트가 버팀 → n=45에서 7.255 정상 잠금.
- **7/4(토) — 여름 기준선 스냅샷 커밋:** 운영 데이터가 누적되지 않는 구조(로그 1MB 덮어쓰기≈2~3주, 평탄 이력 14일 롤링)라 계절 비교용 원본을 `data/baseline/2026-summer/`에 보존(평탄 커브 10런+원시 로그+조건 요약). 겨울 초입에 겨울 스냅샷을 추가해 대조 예정. **★8/4 갱신: 평탄 커브 10런은 `data/dkh_plateau_archive.jsonl`(무기한 보관)로 통합되어 스냅샷 JSON은 제거됨** — 아카이브가 전 필드를 담고 `co2_suspect`·`ref_net_mph`까지 더 갖고 있다. 원시 로그·조건 요약 README는 그대로 남는다(아카이브는 파싱된 궤적만 담아 `[RAW]` ADC·모터·경고 원문이 없음).
- **7/4(토) 오후 — 조명 2배 증강 / 7/5(일) — 에어컨 가동 시작:** 이틀 간격 동시 변경 = 교란 상황. 에어컨=창문 닫힘이라 실내 CO₂가 밤새 축적되는 "냉방 밀폐방" 조건 시작.
- **7/5(일) — 측정 직후 동기화 전환:** WSL cron(측정 시작 +1.5h) 폐지 → 래퍼 `run_measure_and_sync.py`가 측정 완료 직후 sync 호출(부분 데이터 업로드 문제 해소). 7/5 21시·7/6 05시 실전 검증.
- **7/6(월) 05:00 — tank 곡선 상승형 역전(에어컨 계절의 새 기본형):** 본수조가 축적된 실내 CO₂를 흡수해 측정수가 헤드스페이스 대비 CO₂ 과포화로 도착 → 폭기 중 CO₂ 방출 = pH **상승형** 평형 접근(기존 하강형의 거울상, "초기 아래 꼭지" 관찰). **측정 유효성 무영향** — V4 평탄 판정(span/net)은 방향 무관, 62회 정상 잠금 7.115.
- **7/6(월) — 야간 저점의 해석 보류(판별 진행 중):** 7/5 21시 7.161·7/6 05시 7.115 저점이 "하락 추세(−0.25/일)"로 보였으나 13시 7.355 회복. 저점 2개가 하필 야간이고 **ref pH(항상 같은 물 KH 8.83 = pCO₂ 지표)가 그 두 런에서만 하락** = 에어컨 야간 CO₂ 축적과 시점 일치 → 6/16 새벽 −1.09 사례와 같은 "과도 구간 잠금 시 ΔpH 누출" 재발 의심. 판별 = 7/6 21시·7/7 05시에 ref pH 하락+dKH 저점 **동반 재현** 여부(동반=야간 CO₂ 측정 편향 확정, dKH만 낮으면=실제 하락→증량 검토).
- **7/6(월) — 도저 자동 조정·대시보드 설정 구축:** `doser_adjust.py`(월~금 13시 권고 계산, **자동 적용 꺼짐=권고 전용**, 사용자 지시) + 대시보드 수동 도징 설정(5분 폴러 적용, E2E 실증)·목표 dKH 설정(기본 7.2). 첫 권고(13:54): 수준 7.161·추세 −0.005/일 → 6.0→7.8mL/일(+30% 상한) — 사전 예상과 일치, 미적용 정상. 상세: [사용설명서 §10](user-manual.md#10-도저-자동-조정-올포리프)

---

## ★★ 한나 체커 교차검증 — calref 앵커 22일 후 첫 독립 검증 성공 (2026-07-19)

사용자가 한나 dKH 체커로 본수조 물을 실측: **7.7 dKH**. 같은 날 AquaWiz 13시 측정값 **7.687**, 최근 사흘(7/17~7/19) 범위 7.69~7.85 — 실측이 그 한가운데. 차이 ≈ 0.01~0.1 dKH로 목표 오차(±0.5 허용/±0.25 희망)를 크게 밑돎.

- **calref 앵커(6/27 21:00, ref_kh 8.830) 유효성 확인:** 재보정 후 22일 만의 첫 독립 기준측정 교차검증. 앵커 드리프트 없음 — 그동안 절대 정확도가 앵커 1점에 의존한다는 우려(위 6/27 섹션)에 대한 실증적 응답. 단, 핸드테스트 해상도 한계(7/1 사용자 확인: 마지막 자리 확정 불가)는 여전하므로 "0.1 이내 일치"의 정밀한 수치보다 **"7.7대 실재"의 확인**으로 읽는 것이 정확.
- **dKH 수준 7.7대 = 실제 수조 상태로 확정:** "목표(7.2)+0.5"가 계측 착시가 아님. 실도징 2.03mL/일에도 +0.03/일 상승 지속(공급>소비), 13시 권고가 7/15·17·18 사흘 연속 1.5mL/일 감량(하한 캡)을 제시 중이었는데 이번 실측이 그 감량 판단을 독립적으로 뒷받침. 감량 실행 여부는 사용자 판단 대기.

---

## ★★ 측정 방식 개선 — 고정 사전폭기 + 노이즈 차단 측정 (2026-07-23)

기포기 모터의 전기 노이즈가 pH 읽기에 간섭한다는 진단에 따라 "폭기 중 전체 측정"을 하이브리드로 바꿈(사용자 지시, 커밋 `09390d5`). `dkh.dat` 형식·부호·발행 계약은 불변이라 도저·대시보드에 영향 없음.

- **① 읽는 순간만 폭기 OFF(Scheme B):** `measure_until_flat`가 각 read 직전 `airoff` + `SETTLE_SECS`(10초) 정치 후 읽고, 샘플 사이 `MEAS_INTERVAL`(30초) 구간은 `ron` 재폭기로 평형을 유지. 측정 내내 끄는 방식이 아니라 **read 시점만** off → 차동식의 '같은 pCO₂' 전제 보존.
- **② 고정 사전폭기:** tank/ref 각 phase 측정 *전* `PREAERATE_SECS`(tank **1500s=25분**·ref **210s=3.5분**)만큼 먼저 폭기해 평형 근처에 도달. 값 = 완주 이력(tank 51·ref 50런)의 '평탄 도달 중앙값 − net8 확인창' = 런별 `elapsed[flat_n−8]` 중앙값.
- **③ min_n 제거(`FLAT_MIN_N_TANK` 20→0):** false lock은 초기(전극 재평형·열 과도·혼합) 구간에만 생기는데, 그 구간이 이제 사전폭기(측정 전·미측정)에서 지나가므로 근거 소멸. 7/3 도입·7/4·7/17 검증됐던 안전장치를 되돌린 것 — 새 곡선서 초기 조기잠금 재발 시 20 원복.
- **④ `PHASE_MAX_SECS` 7200→5400(=90분, 측정만)·`MEAS_MAX` 240→180:** 사전폭기(총 ~28.5분)가 phase 밖 추가분이라 worst-case 총런을 스케줄러 상한(5h) 아래(~3h45m)로 유지.
- **회귀 검증:** `test_measure_sim.py` **122 PASS**(신규 [23]=사전폭기 호출 + per-read 폭기 토글 검증). 배포 완료(bin→`C:\dkh\work`).
- **⚠️ 미검증(관찰 대기):** 다음 05시(7/24) 첫 실전 런 — 사전폭기 로그·per-read 토글·평탄 잠금·`dkh.dat` 정상 기록·총 런타임 확인 필요. 부수효과 예상: 사전폭기가 ref 평형을 미리 달성 → `ref_flat_n` 분포 하향 → CO₂ 편향 플래그(`ref_flat_n`≥21)가 사실상 휴면화할 수 있음(코드 무변경, 재관찰 후보).
- **✅ 7/24(목) 05:00 첫 실전 검증 성공(전 항목 통과):** 측정 05:00:01 시작 → 05:51 종료(**총 ~51분**, 상한 훨씬 아래). 결과 `05 7.677 7.624 8.830 7.820 29.2` = **dKH 7.820 양수 정상**(reefCore 7.82 발행). ①사전폭기 로그 tank 1500s(25.0분)·ref 210s(3.5분) 실행 ②per-read 토글이 매 샘플 `airoff`→[에어OFF]→정치→`tank` read→`ron`→[참조ON]로 정확히 순환(모터 노이즈 차단 목적 달성) ③평탄 잠금 **tank 9회 O·ref 9회 O**(둘 다 진짜 평탄, span4≤2 AND net8≤1) ④min_n 제거 효과 = 사전폭기 덕에 tank 1회부터 평형 근처(7.626→2·3회 7.625)라 9회 정당 잠금, 구 min_n=20 강제대기 없이도 **초기 조기 false-lock 재발 없음**. dKH 7.820은 최근 추세(7/19 한나 실측 7.7·7/23 7.737)와 정합 → 방식 변경이 계통 오차를 넣지 않음. **부수효과 예상 적중: `ref_flat_n`=9(임계 21 훨씬 아래)로 CO₂ 편향 플래그 휴면화 확인.** (7/23 21시 런은 BT 실패로 에러 래치 → 사용자 수동 제거 후 05시 정상 진행.)

---

## ★★★ 측정기 펌웨어 I2C 행 → 8시간 완전 무응답 사건 + 복구 (2026-07-24~25)

**증상:** 7/24 21시 자동 측정이 `tank` `[START]` 직후 **완전 침묵**(포트는 열리나 펌웨어 무응답). 3시간+ 지속, 호스트 재접속·라디오 disable/enable 전부 무효. **도저(같은 동글)는 정상** → BT/RF 문제 아님. 밤새 방치하니 아침에 **리셋 없이 자연 회복**(`khHist` 보존 = MCU 리셋 아님).

**근본 원인 (실측 재현으로 확정):** 측정기 아두이노가 **ADS1115(pH ADC) I2C 읽기에서 무한 대기**. Adafruit 라이브러리 `readADC_SingleEnded`의 `while(!conversionComplete());`(타임아웃 없음)이 I2C 읽기 실패 시(신호선 접촉 상실) 영원히 spin → loop 정지 → 명령·출력 전부 멎음(= 어제 8시간 침묵). 사용자가 **I2C 신호선 A4(=SDA)를 뽑아 그 침묵을 그대로 재현**함. 물리 뿌리 = SDA/SCL 접점 flaky.

**펌웨어 복구 (`firmware/reefwiz_meter_m1/`, 플래시·검증 완료):**
- `readADSsafe()` = ADS 변환 400ms 상한. `recoverI2C()` = SCL 9펄스 언스틱 → `Wire.begin()` → `ads.begin()` 재초기화. `Wire.setWireTimeout(25ms)`. 부팅 `while(1)` 제거(bounded 재시도). **WDT 8초 안전망**(부팅 `wdt_disable`로 부트루프 방지). 연속 24회 실패 시 측정 중단(응답 유지).
- **진단 `[RAW] min mid max z`** — 트림평균(상·하위 32/64 폐기)이 가리던 나쁜 읽기(z=실패샘플 수)를 노출.
- **검증:** A4 뽑기 → 감지·`[I2C]물림→버스복구`·측정중단·**무행**, 재연결 → **z=0 자가복구**. WDT → 진짜 행 시 **8.1초 클린 리셋**(부트루프 없음·EEPROM 보존). 측정 소스(호스트 파싱) 무영향 = 시뮬 **127 PASS**. **정상 측정값 불변**(`readADSsafe` ≡ `readADC_SingleEnded`, 트림·계산 무변경).

**운영:** 재발 시 `measure_kh.log`에 `[I2C] 물림→버스복구` / `[RAW] z>0` 로그 + 자가복구(8시간 침묵 없음). **근본 수정 = SDA/SCL 접점 재납땜**(펌웨어는 견디게만 함). BT 관점 트러블슈팅은 [bt-reconnect-and-testing.md](bt-reconnect-and-testing.md) 참조.

**★7/25 실측 확인 (재플래시 후 첫 BT 읽기):** 폭기 분배기·도저 펌웨어 재플래시(롤오버 주기밀림 수정, 아래 코드버전 참조) 뒤 측정기 `tank`/`ref` 읽기전용 테스트 → `[RAW] min=11055 mid=11057 max=11058 z=0`(지터 3카운트 = 매우 안정, **z=0 = I2C 물림 0회**)·pH 7.642·T 27.9°C 정상. **신펌웨어 해피패스(`readADSsafe`·`[RAW]` 진단)가 실장치+BT에서 첫 작동 확인** — 단 실제 물림 복구(z>0·버스복구)와 전체 측정 시퀀스는 여전히 미발동(happy-path만). 같은 작업 중 **HC-06 GND 단선**(점검 중이었고 측정 중 아님)으로 COM14 오픈이 `세마포 만료`로 실패 → 선 재연결로 복구(도저 COM12는 내내 정상 = 동글·라디오 무관, 이 세 번째 시그니처는 [bt-reconnect-and-testing.md](bt-reconnect-and-testing.md) 참조).

## 코드 버전 정의

| 버전 | git | 활성 기간 | 폭기 | 대상 | STABLE | CONV_EPS | 토폴로지(시퀀스) | 측정후 지속폭기(terminal ron) | 모터 |
|---|-----|---|---|---|---|---|---|---|---|
| **V0** | `74df769` (6/14 19:30) | 6/14 20:12 – 6/15 05:00 | 1200s | 저장수조(5L)+챔버 | 60 | 0.005 | 구-대칭: tank=챔버(m2), ref=5L→측정컵(m4) | **없음** | m1f:80 / m1b:92 |
| **V1** | `cd7602f` (6/15 10:35) | 6/15 13:00 – 6/16 05:00 | 1200s | 저장수조(5L)+챔버 | 60 | 0.005 | 구-대칭(V0와 동일) | **있음**(다음 측정까지 ron 유지) | m1f:80 / m1b:92 |
| **V1b** | (작업트리, ~6/16 정오) | 6/16 13:00 | 1200s | 저장수조(5L)+챔버 | **120** | **0.002** | 구-대칭(V1과 동일) | 있음 | m1f:80 / m1b:92 |
| **V2** | `b5bb839` (6/16) | 6/16 21:21 – 6/17 05:00 | 1200s | **측정챔버(tank)+홀딩챔버(ref) 동시** | 120 | 0.002 | v2: tank=측정챔버 제자리, ref=홀딩→측정챔버(m2f) 이송. 측정 시 airoff(폭기 OFF) 후 측정 | **없음**(제거) | m1f:60 / m1b:72 |
| **V3** | (작업트리, 6/17) | 6/17 13:00 (→V4 대체) | 1200s + ref 재폭기 **300s** | 측정챔버+홀딩 동시 | **0** | 0.002 | v2 + **측정 중 폭기**(tank·ref 둘 다 ron 유지한 채 수렴) + ref 측정챔버 재폭기 + KCl 헹굼 시 **기포 청소**(CLEAN 60s, 정지 중). STABLE=0 | 없음 | 측정 m1f:70/m1b:82(긴 호스 +10s), 헹굼 m1f:60/m1b:72 |
| **V4** | (작업트리, 6/17) | 6/17 V4배포~ | **평형까지 적응**(고정 폭기시간 없음) | 측정챔버+홀딩 동시 | — | **정수 mpH 윈도우 span ≤2mpH**(최근4, 간격30s) | v3 + **진짜 평형(평탄)까지 측정**(measure_until_flat). 판정=최근 4개 정수 milli-pH의 max−min ≤ 2mpH(윈도우 span). [A]tank 평탄까지(ref 홀딩서 co-aeration) [B]ref 평탄까지(co-aeration이라 빨리). 전이 무대기로 조임. **★무한대기 방지**(PHASE_MAX 2400s·MEAS_MAX 80·연속실패 FAIL_MAX 5·시리얼 타임아웃, 미평탄시 마지막값+경고). 오류시 비상정리(_safe_cleanup=에어OFF+배출+KCl소크). | 없음 | 측정 m1f:70/m1b:82, 헹굼 m1f:60/m1b:72 |

- 공통(전 버전): 측정 1회=64샘플×125ms=8초, 포트 COM15(6/15부터), 펌웨어 차동식.
- **★펌웨어 플래시 완료 (2026-06-17 ~20:50, help로 검증):** 트림평균(TRIM_N=16, 중앙32 평균) + seq/air/wait 제거 + roff/toff + stop + help/status 정리. **이제 전위=트림평균.** ⟹ 절대 pH 성격이 또 바뀜(단순평균→트림평균; 버블 스파이크 제거) — 직접 비교 시 유의(ΔpH/dKH는 무영향). 클론 Nano(CH341)라 신 부트로더(arduino:avr:nano)로 업로드, HC-06이 D0/D1 공유라 보드에서 Nano 빼고 단독 플래시(USB).
- **★하드웨어 규칙(사용자 2026-06-17): 액체 이동(mXf/mXb) 직전엔 반드시 airoff.** 펌웨어상 `ron`=에어(D12)·`ton`=PWM(D13) 독립이고 `airoff`만 둘 다 OFF(ino:646,652-653) — 그래서 V3는 폭기를 *액체 정지 구간*(기포 청소·측정)에만 켜고, 모든 모터 앞엔 airoff.
- **V3 검증 포인트 = 폭기 중 수렴 Δ.** V2까지(폭기 OFF 측정)는 연속 Δ=0.0000. 폭기 중에도 Δ≤0.002로 수렴하면 OK, 0.005~0.02로 튀면 버블 노이즈 과함 → 버블률↓/CONV_EPS 완화.
- **V3 측정 중 폭기 → 절대 pH에 흐름(streaming) 오프셋 포함. V2 이전 절대 pH와 직접 비교 금지**(흐름 오프셋은 ref·tank 공통모드라 ΔpH=dKH엔 무영향, 절대값만 이동).
- 근본 변경 요지: V0→V1 지속폭기. V1→V1b 안정화/수렴 조임. V1b→V2 참조수 소량분취 직접폭기. **V2→V3: 측정 중 폭기로 ref·tank를 같은 pCO₂에 핀고정(차동 CO₂ 상쇄) + ref 측정챔버 재폭기로 경로 대칭 + KCl 기포 청소(baseline).**

---
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

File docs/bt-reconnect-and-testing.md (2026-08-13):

# 블루투스 통신 안정화 (RF 순단 대응) 및 시뮬레이터 회귀 검증

측정(`bin/measure_kh_once.py`)은 PC ↔ AquaWiz 사이를 **HC-06 블루투스 SPP(가상 시리얼 COM 포트)** 로
통신한다. 이 링크가 간헐적으로 끊겨 측정이 실패하던 문제와, 그 대응(코드 4계층 + 예방 keepalive),
그리고 하드웨어 없이 검증하는 소켓 시뮬레이터 회귀 테스트를 정리한다.

> **COM 포트 번호는 수시로 바뀐다**(재페어링·동글 교체·윈도우 업데이트 재열거). 실제 포트는 소스에
> 하드코딩하지 않고 단일 설정 파일 `bt_config.json`에서 읽는다 — [system-setup.md의 BT 포트 설정](system-setup.md#bt-포트-설정--단일-설정-파일-bt_configjson) 참조. 아래 본문의 `COM9`는 최초 진단(2026-06) 당시 값이다.

> 한 줄 요약은 [system-setup.md](system-setup.md#블루투스-통신-안정화--시뮬레이터-검증)에, 사건 기록은
> [measurement-ledger.md](measurement-ledger.md)(6/23 05:00)에 있다.

---

## 1. 문제 — HC-06 SPP RF 순단

- **링크:** 최초(2026-06)에는 COM9 = PC 내장 **인텔 Dual Band Wireless-AC 8265** 의 블루투스 SPP. **2026-07-21부터는 내장 8265의 간헐 장애(콤보칩 버스트) 때문에 USB CSR 동글로 전환**(내장 BT는 "사용 안 함")했고, 실제 COM 번호는 `bt_config.json`이 관리한다.
- **증상:** RF 링크가 간헐(버스트)적으로 끊긴다. 펌웨어는 살아있고, **드롭은 대부분 "명령을 보내려는 순간 이미 끊겨 있음"**(통신 도중엔 잘 안 끊김). 재연결하면 금방 붙고 재페어링·COM 번호 변경은 없다.
- **대표 사건(6/23 05:00):** 자동 측정이 첫 `tank` 측정에서 `[START]` 출력 후 통신이 완전히 멎어 실패(`dkh.dat`에 `05 0.000` 에러 표식). 수동 재실행(05:56)은 정상(`dKH 8.427`).
- **원인:** RF 마진 부족(거리) 아님 — 바로 옆에서도 끊김 → **주변 2.4GHz 간섭**으로 추정. HC-06은 ~20초 무통신 시 링크가 끊기는 경향도 있음(유휴 타임아웃).

### 호스트(Windows)측 조치

| 조치 | 이유 |
|---|---|
| **Wi-Fi 어댑터·BT 네트워크 장치 "사용 안 함"** | 유선랜 사용 중. 같은 콤보칩의 Wi-Fi가 미연결이어도 백그라운드 스캔으로 2.4GHz를 점유해 BT를 방해 |
| **USB 선택적 절전 OFF** (`powercfg ... 48e6b7a6... 0`, AC/DC) | 내장 BT도 내부 USB 버스라, 포트 절전 서스펜드가 RF 드롭을 유발 |
| (참고) 내장 BT 라디오 전원관리 | 이미 "절전을 위해 끔" 비활성 상태 |

---

> **★주의 — "완전 무응답"은 BT가 아니라 측정 펌웨어 I2C 행일 수 있다 (2026-07-24 사건):** 위 RF 순단은 *재연결하면 포트가 다시 열리고 붙는다*. 반면 **포트는 열리는데 펌웨어가 계속 침묵**(도저 등 같은 동글의 다른 장치는 정상)이면 BT가 아니라 **측정기 아두이노가 I2C(ADS1115) 읽기에서 행**일 수 있다 — 신호선 SDA/SCL 접점 상실 → 구펌웨어 `while(!conversionComplete())` 무한 대기 = **8시간 침묵**. 이 경우 호스트 재접속·라디오 리셋은 무효고, **동글을 물리적으로 뽑으면 유령 포트로 악화**된다. 신펌웨어는 `[I2C] 물림→버스복구` / `[RAW] z` 로그와 함께 자가복구(400ms 상한 + 버스복구 + WDT). 상세: [measurement-ledger.md](measurement-ledger.md)의 7/24~25 사건.

> **★주의 — 세 번째 시그니처: 포트를 여는 순간 `세마포 만료(ERROR_SEM_TIMEOUT, WinError 121)`면 HC-06 전원/GND 문제 (2026-07-25 사건):** 앞의 두 경우(RF 순단 = *재연결하면 열림* / I2C 행 = *포트는 열리나 펌웨어 침묵*)와 달리, **`serial.Serial(포트)` 오픈 자체가 세마포 타임아웃으로 실패**하면 원격 HC-06이 RF 응답을 못 하는 것 — 대개 **HC-06 전원/GND 단선**(모듈 미전원)이다. 판별: **같은 동글의 다른 장치(도저 COM12)가 정상 오픈**되면 동글·라디오·페어링은 멀쩡 → 측정기 HC-06 배선 문제로 확정. 조치 = **HC-06 VCC/GND 재체결**(재페어링·포트 재설정 불필요, 포트 매핑 그대로). 7/25 아두이노 재플래시 작업 중 GND가 빠져 발생 → 선 재연결로 즉시 복구.

## 2. 대응 — `measure_kh_once.py`의 `send()` 4계층 + keepalive

모든 펌웨어 명령은 `send()`(모터는 `send_motor()`)를 거친다. RF 순단에 대해 다음을 보장한다.

1. **송신 전 연결 확인** — 모든 명령은 보내기 전 `ensure_link()`(부작용 없는 `status` 핑)로 링크 생존을 확인한다. (드롭이 대개 "보낼 때 이미 끊김"이므로 이 단계가 핵심.)
2. **끊겼으면 재연결** — `reconnect()`가 포트를 `close→open` 하여 HC-06 재연결을 유도하고, `status` 응답으로 복구를 확인한다.
3. **보낸 뒤 연결 문제면 재연결 후 재시도** — 송신/수신 예외 또는 응답 미수신(타임아웃)이면 재연결 후 같은 명령을 재시도한다.
4. **재시도 횟수 상한** — `SEND_RETRY_MAX`(기본 3)회까지. 소진하면 기존 백스톱(측정 `FAIL_MAX`·phase 상한·`_safe_cleanup`·에러 래치)이 처리한다.
5. **모터는 재시도 시 먼저 정지(`mNs`) 후 재송신** — 죽은 링크에 미전달됐든 진행 중이든, 정지 명령으로 멈춘 뒤 재송신해 **펌프 중복 구동(과주입/오버플로)을 방지**한다. (측정·계산·솔레노이드는 멱등/읽기전용이라 그냥 재송신해도 안전.)

**예방 — keepalive:** 측정 간격(30초)·모터 동작(60~85초) 등 유휴 구간 동안 `KEEPALIVE_SECS`(12초)마다 빈 줄(`\r\n`, 펌웨어가 조용히 무시)을 보내 링크를 깨워 둔다 → HC-06 ~20초 유휴 타임아웃 드롭을 애초에 줄인다. 그래도 끊기면 위 4계층이 복구한다.

`calkh`·`calref`(`--setref`)는 동일한 `send()`/측정 루프를 타므로 같은 대응이 자동 적용된다.

### 관련 상수 (실전값)

| 상수 | 기본값 | 의미 |
|---|---|---|
| `RECONNECT_TRIES` | 5 | `reconnect()` 1회당 `close→open` 재연결 시도 횟수(진짜 순단은 1~2회면 붙음) |
| `RECONNECT_BACKOFF` | (1,1,2,2,3) | 재연결 시도별 대기(초). 범위 넘으면 마지막값 유지 |
| `SEND_RETRY_MAX` | 3 | `send()` 1회당 재시도 횟수(튜닝 가능) |
| `KEEPALIVE_SECS` | 12 | 유휴 keepalive 간격(초) — HC-06 ~20초 임계 아래 |
| `MEAS_READ_TIMEOUT` | 20 | 측정 1회 `[OK]` 대기 상한(초). 펌웨어 측정 ~8초이므로 20초면 RF 드롭 판정 |
| `LINK_PING_TIMEOUT` | 3 | `ensure_link`/`reconnect`의 `status` 핑 응답 대기 상한(초) |
| `write_timeout=5` | 5 | 시리얼 write 블로킹 상한(초) — 반열림 BT COM에서 `write()` 무한 블로킹(좀비) 방지 (§2.5) |
| `LINK_RETRY_INTERVAL` | 60 | 평탄 phase 중 링크 완전 사망 시 재접속 시도 간격(초) — phase 마감까지 반복 (§2.5) |

> 펌웨어는 `m1s`~`m4s` 개별 모터 정지를 지원한다(응답 `[Mn] 정지`).

### 2.5 장기 링크 사망 보강 (2026-07-03)

7/2 21시 자동 측정이 도저 설치 작업 중 BT가 장시간 끊기며 실패했다. 사후 분석 결과 단순 실패가
아니라 **좀비**였다: keepalive의 `ser.write()`가 반열림 COM 포트에서 **무한 블로킹**(당시
`write_timeout` 미설정) → 스케줄러 5h 상한(02:00)에 강제 종료 → 에러 행 기록·정리(`_safe_cleanup`)가
전부 미실행. 이에 4종을 보강했다(순단 대응 위에 얹힘, 시뮬 시나리오 [18][19]로 검증).

1. **`write_timeout=5`** — write 블로킹에 상한. `SerialTimeoutException`은 `SerialException`의
   하위라 기존 예외 처리(재연결 경로)가 그대로 받는다.
2. **평탄 phase 중 링크 사망 = 끈질긴 재접속** — `FAIL_MAX` 포기 대신 `_wait_link_recovery`가
   phase 마감(`PHASE_MAX_SECS`)까지 `LINK_RETRY_INTERVAL`(60초) 간격으로 재접속을 시도한다.
   폭기는 유지되므로 평형이 보존되고 모터는 정지 상태라 무해 — 복구되면 측정을 이어간다.
3. **호스트 구제** — 링크 사망으로 `calkh`를 못 불러도 phase 데이터(tank·ref pH)가 온전하면,
   시작 시 `status`에서 캐시해 둔 refKH·온도로 **호스트가 동일 차동식으로 dKH를 계산**해
   **음수 표식**으로 기록·발행한다(0.0 에러 래치 회피). 링크는 살았는데 장비 문제(KCl 소크 실패 등)면
   기존대로 0.0 래치를 유지한다.
4. **스케줄러 등록 파일 정합** — `register_measure_kh.ps1`의 `ExecutionTimeLimit`을 55분(V3
   잔재)에서 5h로 갱신(실제 등록은 이미 5h였고 파일만 낡아 있던 재등록 지뢰 제거).

7/3 13시 첫 실전 런에서 구제 캐시 라인 정상 출력·BT 이벤트 0건으로 확인 완료(링크 사망 경로
자체는 실전 미발생 — 시뮬레이터로만 검증됨).

---

## 3. 시뮬레이터 회귀 검증 (배포 전 필수)

하드웨어 없이 측정 흐름·RF 순단 대응·keepalive·평탄 판정·`calkh`/`calref` 파싱을 상황별로 검증한다.

| 파일 | 역할 |
|---|---|
| `bin/firmware_sim.py` | **소켓 가상 포트 펌웨어 시뮬레이터.** 펌웨어 명령 응답을 충실히 모방. 측정은 상수 pH라 호스트 평탄 판정상 **정확히 8회째 latch**, 모터는 지연 없이 즉시 완료. 펌웨어 상태는 연결을 가로질러 유지(RF 드롭 중에도 살아있는 펌웨어 모사). 드롭/서버 kill/깨진 응답/모터 미완료/먹통 등 예외 주입 가능. 단독 실행(`python3 bin/firmware_sim.py`)으로 수동 접속 테스트도 가능. |
| `bin/test_measure_sim.py` | **통합 회귀 테스트.** 23 시나리오 / 122 검증. |
| `bin/bt_health.py` | (보조) BT 링크 드롭률·RTT 모니터. `--once`(즉석 확인) 또는 연속 로깅. |

### 실행 — WSL, 저장소 안에서

```bash
cd bin && python3 test_measure_sim.py      # WSL python3 + pyserial 3.5 (socket://)
```

> **★규칙: `measure_kh_once.py`(측정·시리얼·RF 순단 로직)나 펌웨어 명령 프로토콜을 바꾸면, 배포
> *전* 항상 이 테스트를 돌려 전부 PASS인지 확인한 뒤 `C:\dkh\work`로 배포한다.** 시뮬레이터·테스트는
> 저장소 `bin/`에만 두고 Windows로 배포하지 않는다.

### 시나리오 (23개 / 112 검증)

**정상/회복 11 시나리오 (60 검증):**

| # | 시나리오 | 검증 수 | 확인 내용 |
|---|---|:---:|---|
| 1 | 클린 측정(calkh) | 9 | 전체 흐름·정확히 8회째 평탄·dKH·모터 8종·재연결 0 |
| 2 | 측정 중 드롭(after) | 6 | 송신 전 연결확인이 다음 측정 전 재연결, 정확도 유지 |
| 3 | 모터 응답 중 드롭 | 5 | 재시도 시 `mNs` 정지 후 재송신(순서 `m1f→m1s→m1f`) |
| 4 | calref(`--setref`) | 6 | ref dKH 역산 경로 견고성 + 수조 dKH=입력값 |
| 9 | 측정 read 중 드롭(before) | 5 | **send 내부 재시도**로 같은 측정 재송신해 성공(tank 9회=8+재송신1) |
| 10 | calref 도중 드롭(setref) | 6 | `setref` 응답 전 드롭 → 재연결+재송신(setref 2회) 후 역산 완주 |
| 13 | calref 기록(평탄) | 3 | `main`이 dkh.dat에 기록(수조 dKH=`--setref` 입력값, 양수) |
| 14 | calref 미평탄 | 3 | 상한 도달 시 dkh.dat 수조 dKH 음수(−입력값) 기록 |
| 19 | 링크 사망→복귀 | 5 | 평탄 phase 중 완전 두절→재기동→끈질긴 대기(§2.5)가 재접속·측정 재개·완주 |
| 20 | 무딘 S커브 MIN_N | 8 | (a) `FLAT_MIN_N_TANK=0`(현 기본, 사전폭기가 초기 lag 흡수 전제)서 저진폭 lag false lock 재현 (b) `=20`이면 참평형 도달·ref 미적용 — min_n 원복 시 동작 문서화(2026-07-23 min_n 제거) |
| 23 | 고정 사전폭기 + read 직전 폭기 토글 | 5 | 측정 전 사전폭기(tank 1500s·ref 210s) 호출 + 각 read 직전 `airoff`·샘플 사이 `ron` 재폭기(2026-07-23) |

**예외 12 시나리오 (60 검증):**

| # | 시나리오 | 검증 수 | 확인 내용 |
|---|---|:---:|---|
| 5 | 완전 통신 두절(서버 kill) | 3 | `main`이 잡는 예외로 우아하게 종료(크래시·행 없음, 상위가 0.0 기록) |
| 6 | 깨진 응답(pH 누락) | 3 | 파싱 실패 → `FAIL_MAX`로 phase 실패(연결 문제 아님 → 재연결 안 함) |
| 7 | 모터 완료 누락(튜브 막힘) | 3 | 재시도(정지+재송신) 소진 후 미완료 처리 |
| 8 | 버스트(연속 2회 드롭) | 4 | 두 번 재연결하며 완주, 정확도 유지 |
| 11 | setref 예외 | 4 | 범위 밖(`--setref 40`)=main 가드가 측정 전 차단 / 펌웨어 `[ERR]` 거부=측정 전 RuntimeError |
| 12 | 모터 정지(`mNs`) 명령 드롭 | 5 | 정지 명령 자체가 드롭돼도 다음 시도에서 재연결·재정지·재송신으로 완료 |
| 15 | calkh 에러 기록 | 1 | 통신 두절→dkh.dat에 0(에러) 표식 기록 |
| 16 | calref 에러 기록 | 1 | calref 실패도 calkh와 동일하게 0(에러) 기록 |
| 17 | 에러 래치 공통 | 4 | calkh·calref 둘 다 래치 발동 시 측정 생략 + 0.0 기록(에러 처리 완전 일치) |
| 18 | 호스트 구제 | 3 | calkh 직전 완전 두절→시작 캐시 refKH로 음수 dKH 기록(0.0 래치 방지, §2.5) |
| 21 | 비상정리 전제조건(airoff·ton) | 7 | 링크 회복 후 전제조건부터 재시도 / 끝내 실패 시 모터 생략(2026-07-10, §2.5 3차 보강) |
| 22 | 비상정리 진행 지점 판단 | 13 | 시작 전=모터 0회 / ref 단계=m4b 회수 / 이송 도중=동결(UNKNOWN sticky, 2026-07-10) |

### 배포 안전 — 테스트 타이밍 패치는 in-memory 한정

테스트는 `import measure_kh_once` 후 `mk.MEAS_INTERVAL=0.02`, `mk.FAIL_MAX=2`,
`mk.MEAS_READ_TIMEOUT=0.5`, `mk.LINK_PING_TIMEOUT=0.3` 등으로 **메모리상 모듈만** 패치해 빠르게
돈다. **소스 파일의 실전 상수는 바뀌지 않으므로**(§2 표) 배포본은 정상 동작한다. 이 분리를 위해
매직넘버를 모듈 상수로 빼 두었다(테스트에서 패치 가능하도록).

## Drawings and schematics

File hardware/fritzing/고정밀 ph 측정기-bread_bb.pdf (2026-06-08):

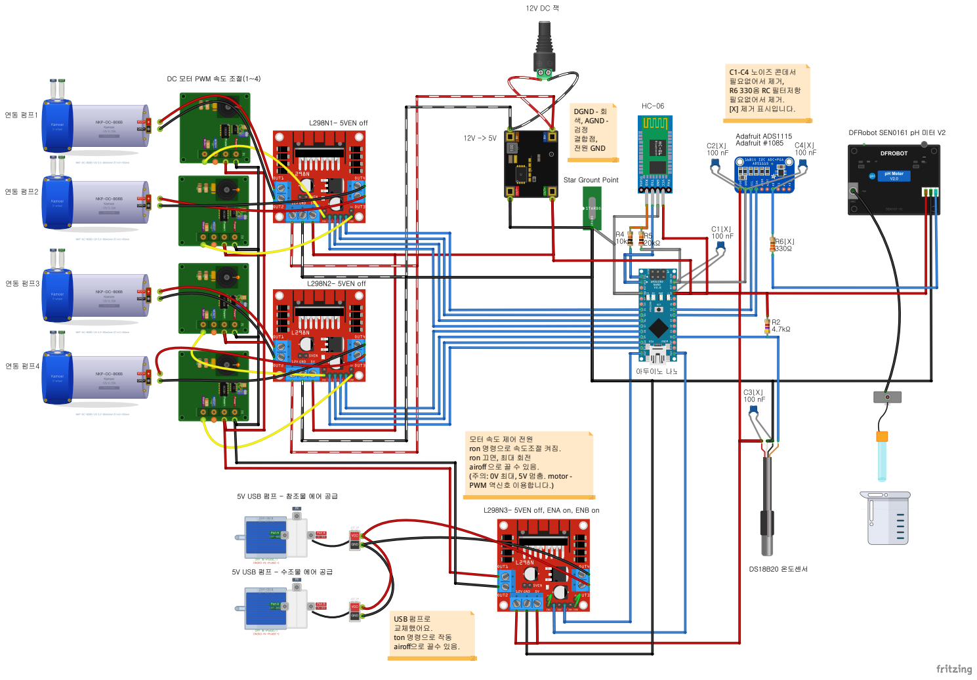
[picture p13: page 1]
DGND - 회 색, AGND - 검정 결합점, 전원 GND; C1-C4 노이즈 콘데서 필요없어서 제거, R6 330옴 RC 필터저항 필요없어서 제거. [X] 제거 표시입니다.

ron 명령으로 속도조절 켜짐.
ron 끄면, 최대 회전
airoff 으로 끌 수 있음.
(주의: 0V 최대, 5V 멈춤. motor-
PWM 역신호 이용합니다.)

USB 펌프로
교체했어요.
ton 명령으로 작동
airoff으로 끌수 있음.

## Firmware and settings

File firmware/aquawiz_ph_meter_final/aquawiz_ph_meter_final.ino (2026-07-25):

/*
 * AquaWiz - pH/dKH 측정 시스템 (탄산염 화학법)
 * KH_tank = KH_ref x 10^(-DeltapH), DeltapH = pH_ref - pH_tank
 * EEPROM: 0x00-0x07 DFRobot_PH, 0x10 refDKH, 0x14 tempOffset, 0x18 calTemp
 */

#include "DFRobot_PH.h"
#include <EEPROM.h>
#include <Wire.h>
#include <Adafruit_ADS1X15.h>
#include <OneWire.h>
#include <DallasTemperature.h>
#include <avr/wdt.h>

// ============================================================
// 핀 정의
// HC-06: 하드웨어 Serial (D0=RX, D1=TX) 직접 연결
// 업로드 시 HC-06 분리 필요
// ============================================================
#define ONE_WIRE_BUS  14
#define M1_IN1        4
#define M1_IN2        5
#define M2_IN3        6
#define M2_IN4        7
#define M3_IN1        8
#define M3_IN2        9
#define M4_IN3        10
#define M4_IN4        11
#define SOL_REF       12
#define SOL_TANK      13

// ============================================================
// EEPROM 주소
// ============================================================
#define REF_DKH_ADDR      0x10
#define TEMP_OFFSET_ADDR  0x14
#define CAL_TEMP_ADDR     0x18

// ============================================================
// 시퀀스/이력 설정
// ============================================================
#define SEQ_CMD_LEN    24
#define CMD_BUF_SIZE   128
#define KH_HIST_MAX    5
#define KH_TIME_LEN    4

// ============================================================
// BTPRINT 매크로 (Serial = 하드웨어 Serial = HC-06)
// ============================================================
#define BTPRINT(x)       Serial.print(x)
#define BTPRINTLN(x)     Serial.println(x)
#define BTPRINTF(x)      Serial.print(F(x))
#define BTPRINTLNF(x)    Serial.println(F(x))
#define BTPRINTFD(v,d)   Serial.print(v,d)
#define BTPRINTLNFD(v,d) Serial.println(v,d)

// ============================================================
// 구조체
// ============================================================
struct KHRecord {
    char  timestamp[KH_TIME_LEN];
    float dkh;
    bool  valid;
};

struct DateTime {
    int           hour;
    bool          valid;
    unsigned long setMillis;
};

struct MotorTimer {
    bool          active;
    int           pinA, pinB;
    unsigned long endTime;
};



// ============================================================
// 객체 선언
// ============================================================
OneWire           oneWire(ONE_WIRE_BUS);
DallasTemperature sensors(&oneWire);
Adafruit_ADS1115  ads;
DFRobot_PH        ph;

// ============================================================
// 오버샘플링
// ============================================================
const int           SAMPLE_N        = 64;
const int           TRIM_N          = 16;   // 트림 평균: 정렬 후 상·하위 각 TRIM_N개 버림(버블 스파이크 제거). 0이면 단순 평균
const unsigned long SAMPLE_INTERVAL = 125;
const unsigned long ADS_CONV_TIMEOUT = 400;   // 정상 변환 125ms(8SPS); 초과 시 I2C 물림 판정→복구
const int           ADS_MAX_FAIL     = 24;    // 측정 중 연속 ADS 실패 한계→측정 중단(펌웨어 응답 유지)

// ============================================================
// 전역 변수
// ============================================================
int           sampleCount    = 0;
float         sampleSum      = 0.0;       // (트림 평균으로 대체 — 리셋 호환 위해 유지)
int16_t       sampleBuf[SAMPLE_N];        // 트림 평균용 raw 샘플 버퍼 (int16×64 = 128 B)
unsigned long lastSampleTime = 0;
bool          voltageReady   = false;
int           adsFailStreak  = 0;         // 연속 ADS 실패(측정 중단 판정)
long          adsFailTotal   = 0;         // 누적 I2C 물림 횟수(진단 로깅)

float voltage     = 0.0;
float phValue     = 0.0;
float temperature = 25.0;
float tempOffset  = 0.0;
float calTemp     = 25.0;
float refDKH      = 0.0;
float refPH       = 0.0;
float tankPH      = 0.0;
float deltaPH     = 0.0;
float tankDKH     = 0.0;

bool refMeasDone  = false;
bool tankMeasDone = false;

enum MeasureMode { MODE_IDLE, MODE_TANK, MODE_REF, MODE_CALIBRATION };
MeasureMode currentMode = MODE_IDLE;

KHRecord  khHist[KH_HIST_MAX];
int       khHistHead  = 0;
int       khHistCount = 0;

DateTime   currentTime;
MotorTimer motorTimers[4];
bool       phCalMode = false;
bool       calphPending = false;

// ============================================================
// Nernst 온도 보상
// ============================================================
float nernstPH(float phRaw, float tempC) {
    return 7.0 + (phRaw - 7.0) * (273.15 + calTemp) / (273.15 + tempC);
}

// ============================================================
// 현재 시각 문자열
// ============================================================
void getTimeStr(char* buf) {
    if (!currentTime.valid) {
        strcpy(buf, "??");
        return;
    }
    unsigned long elapsed = (millis() - currentTime.setMillis) / 3600000UL; // 경과 시간(시)
    int h = (currentTime.hour + (int)(elapsed % 24)) % 24;
    snprintf(buf, KH_TIME_LEN, "%02d", h);
}

// ============================================================
// dKH 이력
// ============================================================
void saveKHRecord(float dkh) {
    KHRecord &r = khHist[khHistHead];
    getTimeStr(r.timestamp);
    r.dkh   = dkh;
    r.valid = true;
    khHistHead = (khHistHead + 1) % KH_HIST_MAX;
    if (khHistCount < KH_HIST_MAX) khHistCount++;
}

void printKHHist() {
    if (khHistCount == 0) { BTPRINTLNF("[KH이력] 없음"); return; }
    BTPRINTF("[KH이력] "); BTPRINT(khHistCount); BTPRINTLNF("개");
    for (int i = 0; i < khHistCount; i++) {
        int idx = ((khHistHead - 1 - i) % KH_HIST_MAX + KH_HIST_MAX) % KH_HIST_MAX;
        KHRecord &r = khHist[idx];
        if (!r.valid) continue;
        char dkhStr[8];
        dtostrf(r.dkh, 6, 3, dkhStr);
        char buf[20];
        snprintf(buf, sizeof(buf), "%2d  %s  %s", i+1, r.timestamp, dkhStr);
        BTPRINTLN(buf);
    }
}

// ============================================================
// 초기화
// ============================================================
void setup() {
    MCUSR = 0; wdt_disable();             // ★부팅 시 워치독 확실히 해제(WDT 리셋 부트루프 방지)
    Serial.begin(9600);  // HC-06 기본 보드레이트
    BTPRINTLNF("=== AquaWiz v3.0 ===");

    sensors.begin();
    if (sensors.getDeviceCount() == 0) BTPRINTLNF("[WARN] DS18B20 없음!");
    else                               BTPRINTLNF("[OK] DS18B20");

    Wire.begin();
    Wire.setWireTimeout(25000, true);     // ★I2C 25ms 타임아웃(물림 시 하드웨어 자동 리셋)
    bool adsOk = false;
    for (int i = 0; i < 5; i++) { if (ads.begin()) { adsOk = true; break; } BTPRINTLNF("[ERR] ADS1115 재시도"); delay(200); }
    if (!adsOk) BTPRINTLNF("[ERR] ADS1115 초기화 실패 — 측정 시 자동 복구");   // ★while(1) 영구정지 제거
    ads.setGain(GAIN_ONE);
    ads.setDataRate(RATE_ADS1115_8SPS);
    BTPRINTLNF("[OK] ADS1115");

    ph.begin();
    BTPRINTLNF("[OK] pH lib");

    EEPROM.get(REF_DKH_ADDR, refDKH);
    if (isnan(refDKH) || refDKH < 0.5 || refDKH > 30.0) {
        refDKH = 0.0; BTPRINTLNF("[WARN] refDKH 없음 → setref:xx.x");
    } else { BTPRINTF("[OK] refDKH: "); BTPRINTFD(refDKH,3); BTPRINTLNF(" dKH"); }

    EEPROM.get(TEMP_OFFSET_ADDR, tempOffset);
    if (isnan(tempOffset) || tempOffset < -10.0 || tempOffset > 10.0) {
        tempOffset = 0.0; BTPRINTLNF("[OK] 온도오프셋: 0.0");
    } else { BTPRINTF("[OK] 온도오프셋: "); BTPRINTFD(tempOffset,2); BTPRINTLNF(" C"); }

    EEPROM.get(CAL_TEMP_ADDR, calTemp);
    if (isnan(calTemp) || calTemp < 0.0 || calTemp > 50.0) {
        calTemp = 25.0; BTPRINTLNF("[OK] 보정온도: 25.0C (기본)");
    } else { BTPRINTF("[OK] 보정온도: "); BTPRINTFD(calTemp,1); BTPRINTLNF("C"); }

    BTPRINTLNF("[INFO] ref 매번 측정 필요");

    int pins[] = {M1_IN1, M1_IN2, M2_IN3, M2_IN4,
                  M3_IN1, M3_IN2, M4_IN3, M4_IN4, SOL_REF, SOL_TANK};
    for (int i = 0; i < 10; i++) { pinMode(pins[i], OUTPUT); digitalWrite(pins[i], LOW); }
    BTPRINTLNF("[OK] 핀 초기화");

    // 구조체 초기화
    currentTime.hour = 0;
    currentTime.valid = false; currentTime.setMillis = 0;

    for (int i = 0; i < 4; i++) {
        motorTimers[i].active = false; motorTimers[i].pinA = 0;
        motorTimers[i].pinB = 0;      motorTimers[i].endTime = 0;
    }
    for (int i = 0; i < KH_HIST_MAX; i++) {
        khHist[i].timestamp[0] = '\0'; khHist[i].dkh = 0.0; khHist[i].valid = false;
    }

    BTPRINTLNF("[READY] 명령대기 (help 입력)");
    wdt_enable(WDTO_8S);                   // ★안전망: loop이 8초+ 멈추면(진짜 행) 자동 리셋
}

// ============================================================
// I2C(ADS1115) 안전 읽기 + 버스 복구 — 간헐 물림이 영구 행이 되지 않게
// ============================================================
void recoverI2C() {
    adsFailTotal++;
    BTPRINTF("[I2C] 물림→버스복구 (누적"); BTPRINT(adsFailTotal); BTPRINTLNF("회)");
    Wire.end();
    // 슬레이브가 SDA를 붙잡고 있으면 SCL 9펄스로 놓게 한 뒤 STOP
    pinMode(SDA, INPUT_PULLUP);
    pinMode(SCL, OUTPUT);
    for (int i = 0; i < 9 && digitalRead(SDA) == LOW; i++) {
        digitalWrite(SCL, LOW);  delayMicroseconds(5);
        digitalWrite(SCL, HIGH); delayMicroseconds(5);
    }
    pinMode(SDA, OUTPUT);
    digitalWrite(SDA, LOW);  delayMicroseconds(5);
    digitalWrite(SCL, HIGH); delayMicroseconds(5);
    digitalWrite(SDA, HIGH); delayMicroseconds(5);   // STOP
    Wire.begin();
    Wire.setWireTimeout(25000, true);
    bool ok = false;
    for (int i = 0; i < 3; i++) {
        if (ads.begin()) { ads.setGain(GAIN_ONE); ads.setDataRate(RATE_ADS1115_8SPS); ok = true; break; }
        delay(50);
    }
    BTPRINTLN(ok ? F("[I2C] 복구 성공") : F("[I2C] 복구 실패(다음샘플 재시도)"));
}

// ADS 채널0 안전 읽기: 변환완료를 시간상한으로 대기. 물림이면 복구 후 *ok=false.
int16_t readADSsafe(bool* ok) {
    ads.startADCReading(ADS1X15_REG_CONFIG_MUX_SINGLE_0, false);
    unsigned long t0 = millis();
    while (!ads.conversionComplete()) {
        if (millis() - t0 > ADS_CONV_TIMEOUT) { recoverI2C(); *ok = false; return 0; }
    }
    *ok = true;
    return ads.getLastConversionResults();
}

// ============================================================
// 메인 루프
// ============================================================
void loop() {
    wdt_reset();                       // ★워치독 리셋(정상 루프는 빨라 안 터짐; 8초+ 진짜 행만 리셋)
    unsigned long now = millis();

    // ① pH 오버샘플링
    if (currentMode != MODE_IDLE && now - lastSampleTime >= SAMPLE_INTERVAL) {
        lastSampleTime = now;
        bool adsOk;
        int16_t raw = readADSsafe(&adsOk);
        if (!adsOk) {                     // I2C 물림·복구 → 이 샘플 건너뜀(측정 계속)
            if (++adsFailStreak >= ADS_MAX_FAIL) {   // 연속 과다 → 측정 중단(펌웨어 응답은 유지)
                BTPRINTLNF("[ERR] ADS 연속 실패 → 측정 중단");
                currentMode = MODE_IDLE; sampleCount = 0; voltageReady = false; adsFailStreak = 0;
            }
            return;
        }
        adsFailStreak = 0;
        if (raw < 0) raw = 0;
        sampleBuf[sampleCount] = raw;     // 트림 평균용: raw 저장 (정렬은 64개 모인 뒤)
        sampleCount++;

        if (sampleCount % 16 == 0) {
            BTPRINTF("  샘플링: "); BTPRINT(sampleCount);
            BTPRINTF("/"); BTPRINTLN(SAMPLE_N);
        }

        if (sampleCount >= SAMPLE_N) {
            // 트림 평균: 삽입정렬 후 상·하위 각 TRIM_N개 버리고 중앙 (SAMPLE_N-2*TRIM_N)개만 평균.
            // computeVolts는 선형이라 raw 트림 평균 = mV 트림 평균과 동일.
            for (int i = 1; i < SAMPLE_N; i++) {
                int16_t key = sampleBuf[i]; int j = i - 1;
                while (j >= 0 && sampleBuf[j] > key) { sampleBuf[j+1] = sampleBuf[j]; j--; }
                sampleBuf[j+1] = key;
            }
            // ★[진단] 트림 전 raw 분포 — 트림에 가린 I2C 나쁜 읽기 노출(정상=min≈mid≈max, 글리치=min0/max극단/z>0)
            int zc = 0; for (int i = 0; i < SAMPLE_N; i++) if (sampleBuf[i] == 0) zc++;
            BTPRINTF("  [RAW] min="); BTPRINT(sampleBuf[0]); BTPRINTF(" mid="); BTPRINT(sampleBuf[SAMPLE_N/2]);
            BTPRINTF(" max="); BTPRINT(sampleBuf[SAMPLE_N-1]); BTPRINTF(" z="); BTPRINTLN(zc);
            float vsum = 0.0;
            for (int i = TRIM_N; i < SAMPLE_N - TRIM_N; i++)
                vsum += ads.computeVolts(sampleBuf[i]) * 1000.0;
            voltage = vsum / (SAMPLE_N - 2 * TRIM_N);
            sampleSum = 0.0; sampleCount = 0; voltageReady = true;

            sensors.requestTemperatures();
            float t = sensors.getTempCByIndex(0);
            if (t == DEVICE_DISCONNECTED_C || t < -10.0 || t > 85.0) {
                BTPRINTLNF("[WARN] DS18B20 오류→25C"); temperature = 25.0;
            } else {
                temperature = t + tempOffset;
            }
            phValue = nernstPH(ph.readPH(voltage, temperature), temperature);
            if (phValue < 0.0 || phValue > 14.0) {
                BTPRINTF("[WARN] pH 이상: "); BTPRINTLN(phValue);
            }
            onSamplingComplete();
        }
    }

    // ② 보정 모드 모니터링 (2초마다 전압/pH 표시)
    static unsigned long calMonTime = 0;
    if (phCalMode && !voltageReady && currentMode == MODE_IDLE && (long)(now - calMonTime) >= 0) {
        calMonTime = now + 2000UL;
        sensors.requestTemperatures();
        float t = sensors.getTempCByIndex(0);
        if (t != DEVICE_DISCONNECTED_C && t > -10.0 && t < 85.0) temperature = t + tempOffset;
        bool adsOk2;
        int16_t raw = readADSsafe(&adsOk2);
        if (!adsOk2) return;
        if (raw < 0) raw = 0;
        float v = ads.computeVolts(raw) * 1000.0;
        float p = nernstPH(ph.readPH(v, temperature), temperature);
        BTPRINTF("  [모니터] V:"); BTPRINTFD(v,3);
        BTPRINTF(" pH:"); BTPRINTFD(p,3);
        BTPRINTF(" T:"); BTPRINTLNFD(temperature,1);
    }

    // ③ 모터 타이머 (millis 오버플로우 안전)
    for (int i = 0; i < 4; i++) {
        if (motorTimers[i].active && (long)(now - motorTimers[i].endTime) >= 0) {
            digitalWrite(motorTimers[i].pinA, LOW);
            digitalWrite(motorTimers[i].pinB, LOW);
            motorTimers[i].active = false;
            BTPRINTF("[모터"); BTPRINT(i+1); BTPRINTLNF("] 완료");
            
        }
    }



    // ⑦ 명령 처리
    handleCommand();
}

// ============================================================
// pH 측정 시작
// ============================================================
void startMeasure(MeasureMode mode) {
    currentMode = mode; voltageReady = false;
    sampleSum = 0.0;    sampleCount = 0;
    lastSampleTime = millis();
    if (mode == MODE_TANK)        BTPRINTLNF("\n[START] 수조수 측정(8초)...");
    if (mode == MODE_REF)         BTPRINTLNF("\n[START] 참조수 측정(8초)...");
    if (mode == MODE_CALIBRATION) BTPRINTLNF("\n[CAL] 보정 측정중...");
}

// ============================================================
// 샘플링 완료
// ============================================================
void onSamplingComplete() {
    BTPRINTLNF("---");
    if (currentMode == MODE_TANK) {
        tankPH = phValue;
        BTPRINTF("[수조수] V:"); BTPRINTFD(voltage,3);
        BTPRINTF(" pH:"); BTPRINTFD(tankPH,3);
        BTPRINTF(" T:"); BTPRINTFD(temperature,1); BTPRINTLNF("C");
        tankMeasDone = true; BTPRINTLNF("[OK]");
        

    } else if (currentMode == MODE_REF) {
        refPH = phValue;
        BTPRINTF("[참조수] V:"); BTPRINTFD(voltage,3);
        BTPRINTF(" pH:"); BTPRINTFD(refPH,3);
        BTPRINTF(" T:"); BTPRINTFD(temperature,1); BTPRINTLNF("C");
        refMeasDone = true; BTPRINTLNF("[OK]");
        currentMode = MODE_IDLE;
        
        return;
    } else if (currentMode == MODE_CALIBRATION && calphPending) {
        BTPRINTF("[CAL] V:"); BTPRINTFD(voltage,3);
        BTPRINTF(" pH:"); BTPRINTFD(phValue,3);
        BTPRINTF(" T:"); BTPRINTFD(temperature,1); BTPRINTLNF("C");
        calphPending = false;
        bool inRange = (voltage>1322&&voltage<1678)||(voltage>1854&&voltage<2210);
        char calCmd[] = "CALPH";
        ph.calibration(voltage, temperature, calCmd);
        if (!inRange) voltageReady = false;
    }
    BTPRINTLNF("---");
    currentMode = MODE_IDLE;
}

// ============================================================
// dKH 계산 + 이력 저장
// ============================================================
void calcAndSaveKH() {
    if (!refMeasDone) { BTPRINTLNF("[ERR] ref 없음");  return; }
    if (refDKH    <= 0.0) { BTPRINTLNF("[ERR] refDKH 없음");  return; }
    if (!tankMeasDone)    { BTPRINTLNF("[ERR] tank 미측정");  return; }

    deltaPH = refPH - tankPH;
    tankDKH = refDKH * pow(10.0, -deltaPH);

    if (tankDKH < 0.0 || tankDKH > 50.0) {
        BTPRINTF("[WARN] dKH 이상:"); BTPRINTLN(tankDKH);
         return;
    }

    char ts[KH_TIME_LEN]; getTimeStr(ts);
    BTPRINTLNF("===[dKH]===");
    BTPRINTF("  시각:"); BTPRINTLN(ts);
    BTPRINTF("  참조pH:"); BTPRINTLNFD(refPH,3);
    BTPRINTF("  수조pH:"); BTPRINTLNFD(tankPH,3);
    BTPRINTF("  dPH:"); BTPRINTLNFD(deltaPH,4);
    BTPRINTF("  refKH:"); BTPRINTFD(refDKH,3); BTPRINTLNF(" dKH");
    BTPRINTF("  수조KH:"); BTPRINTFD(tankDKH,3); BTPRINTLNF(" dKH");
    BTPRINTF("  온도:"); BTPRINTFD(temperature,1); BTPRINTLNF("C");
    BTPRINTLNF("===========");

    saveKHRecord(tankDKH);
    BTPRINTF("[OK] 이력저장 총"); BTPRINT(khHistCount); BTPRINTLNF("개");

    tankMeasDone = false; refMeasDone = false;
    
}

// ============================================================
// 참조 dKH 역산 (수조 dKH 기준)
// setref에 저장된 값을 수조 dKH로 간주하여 참조 dKH를 계산
// ============================================================
void calcRefDKH() {
    if (!refMeasDone) { BTPRINTLNF("[ERR] ref 없음"); return; }
    if (refDKH    <= 0.0) { BTPRINTLNF("[ERR] setref 없음 (수조dKH 입력)"); return; }
    if (!tankMeasDone)    { BTPRINTLNF("[ERR] tank 미측정"); return; }

    float knownTankDKH = refDKH;
    deltaPH = tankPH - refPH;
    float newRefDKH = knownTankDKH * pow(10.0, -deltaPH);

    if (newRefDKH < 0.5 || newRefDKH > 30.0) {
        BTPRINTF("[WARN] refDKH 이상:"); BTPRINTLN(newRefDKH);
        return;
    }

    char ts[KH_TIME_LEN]; getTimeStr(ts);
    BTPRINTLNF("===[calref]===");
    BTPRINTF("  시각:"); BTPRINTLN(ts);
    BTPRINTF("  참조pH:"); BTPRINTLNFD(refPH,3);
    BTPRINTF("  수조pH:"); BTPRINTLNFD(tankPH,3);
    BTPRINTF("  dPH:"); BTPRINTLNFD(deltaPH,4);
    BTPRINTF("  새refDKH:"); BTPRINTFD(newRefDKH,3); BTPRINTLNF(" dKH");
    BTPRINTF("  수조dKH:"); BTPRINTFD(knownTankDKH,3); BTPRINTLNF(" dKH");
    BTPRINTF("  온도:"); BTPRINTFD(temperature,1); BTPRINTLNF("C");
    BTPRINTLNF("===============");

    refDKH = newRefDKH;
    EEPROM.put(REF_DKH_ADDR, refDKH);
    BTPRINTF("[OK] refDKH 저장:"); BTPRINTFD(refDKH,3); BTPRINTLNF(" dKH");

    tankMeasDone = false; refMeasDone = false;
    BTPRINTLNF("[INFO] ref/tank 재측정 필요");
}

// ============================================================
// 모터 제어
// ============================================================
void motorRunTimed(int idx, int pinA, int pinB, bool fwd, long sec) {
    if (sec <= 0 || sec > 3600) {
        BTPRINTLNF("[ERR] 모터시간 1~3600초");
         return;
    }
    if (motorTimers[idx].active) {
        digitalWrite(motorTimers[idx].pinA, LOW);
        digitalWrite(motorTimers[idx].pinB, LOW);
    }
    digitalWrite(pinA, fwd ? HIGH : LOW);
    digitalWrite(pinB, fwd ? LOW  : HIGH);
    motorTimers[idx].active  = true;
    motorTimers[idx].pinA    = pinA;
    motorTimers[idx].pinB    = pinB;
    motorTimers[idx].endTime = millis() + (unsigned long)sec * 1000UL;
    BTPRINTF("[M"); BTPRINT(idx+1);
    if (fwd) BTPRINTF("] 정방향 "); else BTPRINTF("] 역방향 ");
    BTPRINT(sec); BTPRINTLNF("초");
}

void motorStopNow(int idx, int pinA, int pinB) {
    digitalWrite(pinA, LOW); digitalWrite(pinB, LOW);
    motorTimers[idx].active = false;
    BTPRINTF("[M"); BTPRINT(idx+1); BTPRINTLNF("] 정지");
}

void motorAllStop() {
    motorStopNow(0,M1_IN1,M1_IN2); motorStopNow(1,M2_IN3,M2_IN4);
    motorStopNow(2,M3_IN1,M3_IN2); motorStopNow(3,M4_IN3,M4_IN4);
}

// ============================================================
// 에어/PWM 핀 OFF (airoff 용)
// ============================================================
void stopAir() {
    digitalWrite(SOL_REF, LOW); digitalWrite(SOL_TANK, LOW);
}
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

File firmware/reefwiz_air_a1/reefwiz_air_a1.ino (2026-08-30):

/*
 ReefWiz Air A-1 (RWA1) - 포드류 배양을 위한 공기 토출 분배기 V3.0
  - 모드 드라이버 L298N 으로 두 개의 소형 솔레노이드 밸브 제어
  - 기본 코드는 칼슘리액터 출력기를 이용.
  - EEPROM 저장 기능, Run Time 을 초 단위에서 1/1000 초로 수정
  - millis() 타이머가 계속증가하다가 최대치에서 다시 0 으로 될때, 타이머 재설정 추가
  - ms 시간 변환 #define 문법 오류 수정 및 help 추가
  - claude 버그, watch_doc, lazy_timer 주소 호출, EEPROM.write update 변경, 주석 호출 수정
  - refresh_all_timers() 에서 lazy_timer는 reset이 포함되어 중복 배제
  - claude 버그, r/l/rr/ll test 큰 값(예:100000) 입력 시 16bit int 오버플로우로 밸브 안멈추는 문제 수정(long으로 변경)
  - claude 버그, r/l/rr/ll gt/rt 도 동일한 오버플로우 패턴 있어 clamp_to_uint16()로 0~65535 클램프 추가
  - claude 버그, set time hh:mm:ss 도 동일 패턴(int hh,mm,ss) 있어 long+범위클램프로 수정
  - claude 버그, "rrtest" 명령이 "rrt" 핸들러에도 걸려 R RUN 시간이 0으로 덮어써지던 파싱 충돌 수정
  - claude 개선, 명령은 개행(\n) 완성 시에만 처리(BT 순단 시 잘린 명령 오저장 방지), 수신 delay(5) 제거(연속 수신 시 loop 독점 방지), 64자 상한
  - claude 개선, debug reset의 timer0_millis 쓰기 인터럽트 보호, startup() 참조 전달로 변경
  - claude 개선, 문자열 리터럴 F() 매크로로 플래시 이동(SRAM 절약), cmdString.reserve(64), help/주석 단위 표기 실제 코드와 일치(gt=초, rt/test=ms)
  - claude 개선, 롤오버 시 refresh_all_timers() 제거(위 6번 항목 재검토): SimpleTimer.isReady()가 (millis()-_previous)를 부호 없는 32비트 뺄셈으로 비교하므로 millis() 롤오버(≈49.7일)를 스스로 정확히 넘긴다. 롤오버마다 타이머를 리셋하면 진행 중이던 GAP 카운트다운이 버려져 ~49.7일에 1회 토출(밸브 동작)이 최대 1주기 늦춰지는 '주기 밀림'이 있었음. Diff_Time(로그 시각) 보정은 유지, setup()·"refresh all" 명령에서의 호출은 필수라 그대로 둠
  - claude 기능, ver 명령 추가(기기 버전 한 줄) + 부팅 배너·help 첫 줄을 기기 버전으로 통일
 이태석, 2024.9.28, 2025.5.29, 2025.10.9, 2025.12.13, 2026.7.2, 2026.7.24
*/

// ============================================================
// 기기 식별 (ver 명령 / 부팅 배너 / help 첫 줄)
//   FW_COMMIT: 플래시 직전 `git rev-parse --short=6 HEAD` 값(대문자)으로 갱신
// ============================================================
#define FW_CODE     "RWA1"
#define FW_NAME     "ReefWiz Air A-1"
#define FW_VERSION  "1.0.0"
#define FW_COMMIT   "55DAFC"
#define FW_VERSTR   FW_NAME " v" FW_VERSION " #" FW_COMMIT

#include <SoftwareSerial.h>
#include <EEPROM.h>
#include <SimpleTimer.h>
#include <avr/wdt.h>

// Create a first&sceond timer and specify its interval in milliseconds
SimpleTimer firstTimer;
SimpleTimer secondTimer;
// Run timer
SimpleTimer firstRunTimer;
SimpleTimer secondRunTimer;
// Test timer
SimpleTimer firstTestTimer;
SimpleTimer secondTestTimer;
// Create a ffirst&ssceond timer and specify its interval in milliseconds
SimpleTimer ffirstTimer;
SimpleTimer ssecondTimer;
// Run timer
SimpleTimer ffirstRunTimer;
SimpleTimer ssecondRunTimer;
// Test timer
SimpleTimer ffirstTestTimer;
SimpleTimer ssecondTestTimer;
// A flag indicates, that a run and test timer is ready
bool firstFlag = false;
bool secondFlag = false;
bool firstRunFlag = false;
bool secondRunFlag = false;
bool firstTestFlag = false;
bool secondTestFlag = false;
bool ffirstFlag = false;
bool ssecondFlag = false;
bool ffirstRunFlag = false;
bool ssecondRunFlag = false;
bool ffirstTestFlag = false;
bool ssecondTestFlag = false;

//Motor right
const int motorPin1 = 9; // IN1_ L298n=>D9
const int motorPin2 = 10; // IN2_ L298n=>D10

//Motor left
const int motorPin3 = 5; // IN3_ L298n=>D5
const int motorPin4 = 6; // IN4_ L298n=>D6

// Motor Control : motorSet1, motorSet2
// 오른쪽 Motor : motorPin1,motorpin2 
// 왼쪽 Motor : motorpin3,motorpin4

// 모터의 힘을 조절하는 값 - PWM 아날로그 출력
// USB 5V전원을 USB 단자로 공급, 양쪽 6V 솔레노이드 제어를 위해 100%로 출력한다.
const int R_POWER = 255; // 50+알파, 구동 전압의  1/4 출력 24V 일때, 5~6V
const int L_POWER = 255; // 250이면, 구동 전압의 100% 출력 24V 일때, 24V

const int blueTx = 2;   //Tx (보내는핀 설정)
const int blueRx = 3;   //Rx (받는핀 설정)

String cmdString = ""; //받는 문자열
SoftwareSerial BTSerial(blueTx, blueRx);      // 블루투스 시리얼 통신을 위한 객체선언
//#define BTSerial Serial

/** the current address in the EEPROM (i.e. which byte we're going to write to next) **/
const int R_GT_addr = 0;
const int R_RT_addr = 16;  // 2 번 주소 값 저장이 안되는 오류 발생, 주소 변경
const int L_GT_addr = 4;
const int L_RT_addr = 6;
const int RR_GT_addr = 8;
const int RR_RT_addr = 10;
const int LL_GT_addr = 12;
const int LL_RT_addr = 14;

#define M2msR(x) ((unsigned long)(x) * 60UL * 1000UL)  // 오른쪽 모터용 변환, 1 분
#define M2msL(x) ((unsigned long)(x) * 60UL * 1000UL)  // 왼쪽 모터용 변환, 1 분
#define S2msR(x) ((unsigned long)(x) * 1000UL)  // 1 초
#define S2msL(x) ((unsigned long)(x) * 1000UL)  // 1 초
#define S2ms(x) ((unsigned long)(x) * 1UL)  // x가 ms 로 들어오게 코딩함, 변환 안함.
#define D2ms(x) ((unsigned long)(x) * 24UL * 60UL * 60UL * 1000UL)  // 1 일

unsigned long R_Gap_Time = S2msR(10);                // 동작 주기(GAP), 단위: 초 (S2ms* = *1000)
unsigned long R_Run_Time = S2ms(12);                 // 동작 시간(RUN), 단위: ms (S2ms = 변환 없음)
unsigned long L_Gap_Time = S2msL(10);                // 동작 주기(GAP), 단위: 초 (S2ms* = *1000)
unsigned long L_Run_Time = S2ms(12);                 // 동작 시간(RUN), 단위: ms (S2ms = 변환 없음)
unsigned long RR_Gap_Time = S2msR(10);                // 동작 주기(GAP), 단위: 초 (S2ms* = *1000)
unsigned long RR_Run_Time = S2ms(12);                 // 동작 시간(RUN), 단위: ms (S2ms = 변환 없음)
unsigned long LL_Gap_Time = S2msL(10);                // 동작 주기(GAP), 단위: 초 (S2ms* = *1000)
unsigned long LL_Run_Time = S2ms(12);                 // 동작 시간(RUN), 단위: ms (S2ms = 변환 없음)

unsigned long Diff_Time = 0;  // 현재시간 유지 보정값
unsigned long prev_time = 0;  // loop에서 이전 시간 저장
unsigned int tHH, tMM, tSS, tMI;

unsigned int EEPROM_readInt(unsigned int addr)
{
  union
  {
    byte b[2];
    unsigned int f;
  } data;
  for (int i = 0; i < 2; i++)
  {
    data.b[i] = EEPROM.read(addr + i);
  }
  return data.f;
}
void EEPROM_writeInt(unsigned int addr, unsigned int x)
{
  union
  {
    byte b[2];
    unsigned int f;
  } data;
  data.f = x;
  for (int i = 0; i < 2; i++)
  {
    EEPROM.update(addr + i, data.b[i]); // 값이 다를 때만 저장, 쓰기 횟수 보호
  }
}

// EEPROM에는 unsigned int(16bit, 0~65535)로만 저장되므로, 입력값을 그 범위로 클램프한다.
// (클램프 없이 unsigned int에 직접 대입하면 예: 100000 → 34464 로 조용히 랩어라운드됨)
unsigned int clamp_to_uint16(long v) {
  if (v < 0) return 0;
  if (v > 65535L) return 65535;
  return (unsigned int)v;
}


// 타이머를 사용하지 않을 때, 끄는 기능이 없으므로, 20일에 한번씩 천천히 작동하게 한다.
void lazy_timer(SimpleTimer &x) {   // & 추가
  unsigned long a_month = D2ms(20);
  x.setInterval(a_month);
  x.reset();
}

void set_HHMMSSMI(unsigned long mili_time) {
  unsigned long readTime;

  readTime = mili_time/1000;

  tMI = mili_time%1000;
  tSS = readTime%60;
  tMM = (readTime/60)%60;
  tHH = (readTime/(60*60))%24;
}

unsigned long trunc_less_24h(unsigned long mili_time) {
  unsigned int hh, mm, ss, mi;
  unsigned long readTime;

  readTime = mili_time/1000;

  mi = mili_time%1000;
  ss = readTime%60;
  mm = (readTime/60)%60;
  hh = (readTime/(60*60))%24;

  return ((long)hh*3600+mm*60+ss)*1000+mi;
}
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

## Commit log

2026-05-30 Clarify KCL 3% as pH probe storage solution, not cleaning
    KCL 3% solution keeps the pH probe submerged to prevent drying.
    Pump 3 supplies/drains KCL storage water before and after measurement.
2026-05-30 Fix SVG viewBox overflow and minor cleanup
    - piping-diagram.svg: increase viewBox height 500→520 (D13/Air2 labels were clipped)
    - system-setup.svg: remove unused marker def
    - README.md: add piping-diagram.svg to project tree listing
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2026-05-30 Fix backward arrow directions and rename 배관→호스
    - Replace _rev markers with normal markers on backward lines
    (orient=auto with _rev on left-going lines caused arrows to flip)
    - Rename all 배관 references to 호스
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2026-05-30 Fix khhist output: use dtostrf instead of snprintf %f on AVR
    AVR libc's snprintf does not support %f format, causing dKH values
    to display as '?' in khhist output. Replaced with dtostrf().
    [aquawiz_ph_meter_final.ino]
2026-05-30 Fix parts list: correct AliExpress URL, add target=_blank links, update pump image
    - AliExpress URL fixed to correct product (1005001888639071)
    - All purchase links open in new tab (target="_blank")
    - Pump image replaced with actual product photo from AliExpress
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2026-05-30 Redesign README for first-time visitors
    - Add feature highlights (7 key points) at the top
    - Add visual gallery: system diagram, piping, circuit, housing in 2x2 grid
    - Compact pin assignments and power section
    - Add document navigation table
    - Keep setup-demo.svg as hero image
2026-05-30 Fix power diagram: L298N3 runs on 6V for solenoid valves
    Solenoid valves (ZHY-0519) are 6V DC rated. L298N3 motor supply
    connects to XL4015 Buck 6V output, not 12V directly.
    L298N1/L298N2 remain on 12V for peristaltic pumps.
2026-05-31 Reject truncated commands instead of executing them
    Truncated commands could cause unexpected side effects (e.g. partial
    seq running incomplete steps). Now prints error and returns without
    executing.
    [aquawiz_ph_meter_final.ino]
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2026-05-31 Update Fritzing schematic with noise filter components
    Added C1(100nF Arduino), C2(100nF ADS1115 VDD), R6(330ohm)+C4(100nF)
    RC input filter on pH signal path. Regenerated PNG preview.
    [고정밀 ph 측정기-bread.fzz]
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2026-05-31 Fix stack overflow: eliminate recursive advanceSeq calls
    advanceSeq() previously called executeSeqStep() recursively.
    With 20 immediate commands (e.g. settime), recursion depth = 20,
    requiring ~2470B stack vs 443B available = OVERFLOW.
    Fix: advanceSeq() sets seqAdvancePending flag, loop() processes
    next step in the next cycle. Max stack depth is now constant.
    [aquawiz_ph_meter_final.ino]
2026-05-31 Fix pH calculation: use measured refPH instead of recalculating
    refPH was being recalculated with current temperature in calcAndSaveKH
    and onSamplingComplete, but refVoltage was generated at ref measurement
    temperature. Using stored refPH (correctly Nernst-compensated at
    measurement time) eliminates temperature mismatch error.
    Verified: 2-point calibration, Nernst compensation, dKH formula all
    mathematically correct. Error < 0.00004 dKH at same temperature.
    Flash 93% (-202B), RAM 77% unchanged.
    [aquawiz_ph_meter_final.ino]
2026-05-31 Update EEPROM map in docs and firmware header
    Added calTemp at 0x18~0x1B, fixed address ranges for existing entries.
    [aquawiz_ph_meter_final.ino]
2026-05-31 Add measurement accuracy analysis to system-setup docs
    Nernst compensation verified: 0% error across 15-35°C range.
    System accuracy: ±0.07 dKH (±1.2%), dominated by pH probe repeatability.
    ADC resolution: ±0.001 dKH after 64x oversampling.
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2026-06-01 Redesign setup-demo SVG and update Fritzing schematic
    - setup-demo.svg: completely rebuilt with correct hose routing
    (M3/M4 through pH beaker), air distributor with AIR label,
    accuracy badge, cleaner layout
    - Fritzing: updated fzz/pdf/png with latest schematic
    [고정밀 ph 측정기-bread.fzz]
2026-06-03 Replace boot help with ready message
    [aquawiz_ph_meter_final.ino]
2026-06-03 Fix calcref: reset session after execution to prevent cumulative error
    Repeated calcref calls caused refDKH to drift because the updated
    refDKH was used as knownTankDKH in the next call. Now resets
    tankMeasDone/refMeasDone after calcref, requiring re-measurement.
    [aquawiz_ph_meter_final.ino]
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2026-06-03 Fix calTemp protection: require enterph before calph/exitph
    Added phCalMode flag. calph/exitph without enterph now shows
    "[ERR] enterph 먼저 실행" and does not overwrite calTemp.
    Prevents accidental calTemp change from stray exitph commands.
    [aquawiz_ph_meter_final.ino]
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2026-06-03 Fix critical: send ENTERPH to DFRobot library on enterph
    Without this, the library's enterCalibrationFlag was never set,
    causing calph and exitph to be silently ignored by the library.
    Calibration appeared to work but values were not actually updated.
    [aquawiz_ph_meter_final.ino]
2026-06-03 Add temperature reading to calibration monitor
    Monitor now reads DS18B20 for accurate Nernst-corrected pH display.
    Output: [모니터] V:2047.9 pH:3.88 T:28.1
    Flash 99% (162B remaining), RAM 78%.
    [aquawiz_ph_meter_final.ino]
2026-06-03 Fix: reset voltageReady on enterph so monitor always works
    After previous ref/tank measurements, voltageReady was true,
    blocking the calibration monitor. Now enterph resets it.
    [aquawiz_ph_meter_final.ino]
2026-06-03 Add measured stability data: pH ±0.0005, voltage ±0.061mV
    Real-world test results from 5 consecutive measurements in KCL
    solution, near ADS1115 16-bit theoretical limit.
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2026-06-03 Resize app icon to 40x40, clarify Nano EMI rationale and ESP32 expansion
    - BT terminal icon: 20x20 → 40x40 (half of original 80x80)
    - Arduino Nano chosen for minimal EMI interference
    - ESP32 expansion for Wi-Fi, web dashboard, data logging
2026-06-07 Prevent calTemp save when calph fails (buffer out of range)
    If measured voltage is outside pH 4.0 (1854-2210) and pH 7.0
    (1322-1678) ranges, voltageReady is reset to false. Subsequent
    exitph will cancel instead of saving calTemp.
    [aquawiz_ph_meter_final.ino]
2026-06-08 회로도 수정, 온도센터 실드 연결
    [고정밀 ph 측정기-bread.fzz]
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2026-06-12 Symmetric KH measurement: tank-first sequence with convergence detection
    measure_kh_once/loop: aerate storage tank (5L) directly while probe
    rests in KCl; measure tank first (KCl sweep doubles as rinse), then ref
    with identical rinse/fill/stabilize timing so electrode response lag
    cancels as common mode. Replace single-shot ref/tank reads with
    convergence loop (45s interval, <0.003 pH, max 6) — count logged as
    electrode health indicator. dkh.dat format unchanged.
    Docs: rewrite system-setup measurement sequence for the symmetric
    design, switch probe storage solution KCL 3% -> 3M KCl across docs/SVGs.
    [measure_kh_loop.py, measure_kh_once.py]
2026-06-14 Tune pump timings, shorten aeration, relax convergence eps
    - 헹굼(rinse) forward 30→60, back 38→68 for m2/m4: full-immersion
    rinse so the measuring cup inner wall is wetted; tank/ref kept symmetric
    - m1f:80 (long hose sampling), m1b:92 (+12s to clear long hose)
    - AIR_SECS 1800→1200 (30→20min): widens hourly margin to ~16-22min
    - CONV_EPS 0.003→0.005: noise floor measured ~0.001-0.002 pH, so
    3-5x noise converges reliably in 2-3 reads; dKH impact ~0.05
    [measure_kh_once.py]
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2026-06-17 ledger: design principle — system must reject room CO2, not depend on ventilation
    Ventilation is a diagnostic, not a fix. The differential design must
    cancel room CO2 as a common-mode variable; the real defect is that it
    doesn't (ref/tank asymmetry). Drop the ventilation experiment.
    Real fix = restore symmetry so ref and tank reach the same pCO2
    regardless of room CO2: co-equilibrate ref in the same chamber as
    tank (A), or match the reference time constant via small volume (C).
2026-06-17 ledger: v2 already uses matched small volumes — falsify volume hypothesis
    User confirms 6/17 05:00 measured ref and tank as small equal-volume
    aliquots (both 60s pump). So the small-volume / time-constant match
    (option C) is effectively already implemented in v2, yet the dawn
    error persisted (-0.058). Therefore volume/time-constant asymmetry is
    not the v2 residual cause. Remaining suspects are non-volume: the
    holding-vs-measurement chamber+airstone difference, and the sequential
    read timing. Next test = option A (co-equilibrate ref in the same
    measurement chamber/airstone as tank).
2026-06-17 ledger: real setup — tank is a 200mL open chamber, not the live reef
    The "tank" is a separate 200 mL external chamber open to room air
    (a tank simulator); ref is the 5L semi-enclosed kimchi tub; both hold
    the same water (null test, split 6/14 20:12). So -0.058 is the
    time-constant asymmetry between the small open 200mL (fast tracker of
    room CO2) and the large semi-enclosed 5L (slow lag) — the original
    "tank fast / ref slow" model. The earlier "volume ruled out" was wrong:
    the measurement aliquots are equal, but the asymmetry lives in the
    source vessels. The differential should cancel it via full aeration to
    a common pCO2 (equilibrium is volume-independent), so the residual means
    1200s ae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
2026-06-17 firmware: tidy help/status — drop obsolete air/wait, add direct controls
    help/status now reflect the real operational command set:
    - help: add the direct pin controls (ron/roff air, ton/toff PWM, airoff);
    drop the obsolete air:/wait: lines (commands kept in code, just not
    advertised since they're unused/legacy from the solenoid era).
    - status: replace the legacy [에어](alternation)/[대기] readouts with a
    live pin-state line — 에어(D12) and PWM(D13) ON/OFF via digitalRead,
    which actually reflects ron/roff/ton/toff.
    [aquawiz_ph_meter_final.ino]
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2026-06-17 test_aeration_plateau: simplify prep, always restore KCl on exit
    - It's a test, so drop the KCl rinse + bubble-clean from prep; prep is
    now just drain KCl (m3b) -> fill sample (m1f). Removed the now-unused
    RINSE/CLEAN params.
    - Guarantee the probe is left in KCl: move cleanup (drain sample -> fill
    KCl solution -> airoff) into a try/finally so it runs on every exit
    path — normal completion, Ctrl+C, or error. Removed the CLEANUP_KCL
    flag and the partial Ctrl+C-only airoff handler.
    [test_aeration_plateau.py]
2026-06-17 KH V4: plateau-tracking measurement (window-flat) with infinite-wait guards
    Replace fixed aeration + consecutive-Δ convergence with "measure during
    aeration until truly flat" (window-flatness: last 4 reads max-min ≤
    0.002, validated on the plateau CSV). Both tank and ref are driven to
    their true plateau so the differential cancels room CO2 regardless of
    the start gap (auto-adapts to the gap, no fragile extrapolation).
    Sequence: [A] aerate both, measure tank to flat (ref co-aerates in the
    holding chamber meanwhile) -> tight no-wait transition (airoff, full
    m1b:82 drain for contamination safety, m2f transfer) -> [B] measure ref
    to flat (fast, since co-aerated near plateau) -> calkh.
    Infin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
    [measure_kh_once.py]
2026-06-17 V4: verify KCl soak; log 0.0 error marker if cleanup/soak fails
    A silent KCl-soak failure on the normal path (m3f times out / no
    response) previously logged a valid value with no error flag, leaving
    the probe possibly un-soaked and undetected. Now the KCl soak's
    completion ([모터3] 완료) is verified: if it fails, run_measurement
    raises -> _safe_cleanup retries the soak (and shouts if it also fails)
    -> main records "HH 0.000 0.000 0.000 0.000 0.0" in dkh.dat as the error
    marker. So any failure including the KCl soak is visible. Adds
    _motor_ok() helper.
    [measure_kh_once.py]
2026-06-17 ledger: V4 first run reveals equilibrium drift during the long measurement
    17:08 manual V4 run (evening): ΔpH -0.063 (worse than V3 -0.058). The
    tank curve was non-monotonic — rose to 8.077 (16 min) then FELL to 8.043
    (31 min) — because room CO2 (the equilibrium) drifted during the 31-min
    measurement. ref, measured ~25 min later, latched at 8.106; tank and ref
    thus latched under different room-CO2 conditions, so -0.063 is an
    inter-phase drift artifact, not the true KH.
    Core conflict exposed: V4's "measure to plateau" (~30 min/phase) widens
    the tank↔ref gap to ~25 min, worsening the drift residual — directly
    opposing the goal of tightening that gap. Full-plateau (long) vs
    tight-gap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
2026-06-17 ledger: plateau retest (door open) clean & monotonic — drift is the variable
    19:42 retest: 8.005 -> 8.062 monotonic, plateau at 1053s (~17.5 min),
    flat. None of the 17:08 non-monotonic hump. Both runs had the door open,
    yet 17:08 drifted and 19:42 was stable — so the deciding factor is
    whether room CO2 is stable DURING the measurement, not the door. Confirms
    the side points too: plateau value tracks room CO2 (8.062/8.077/8.100),
    plateau time tracks the start gap (17.5 min @ 0.057 vs 24 min @ 0.100,
    i.e., not always 24 min). Reinforces: V4 plateau-tracking works fine when
    CO2 is stable; the robust fix for the drift case is stabilizing the
    aeration gas so the equilibrium is fixed regardles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
2026-06-20 ref-먼저+호스스왑 측정 흐름 + 6/20 통제실험(장치 가설 4개 기각)
    - measure_kh_once.py: 호스 스왑 배관(m4=5L↔측정챔버, m1=본수조↔홀딩)
    + ref 먼저 측정(천장확정/웜업) → tank 나중 순서로 재작성.
    _safe_cleanup 도 새 배관에 맞춰 m2b(측정챔버→홀딩)→m1b(홀딩→본수조)로 수정.
    - ledger: 6/20 18:11(2배폭기 tank-먼저 −0.055) + 18:57(2배폭기 ref-먼저 −0.044)
    통제실험 2점 기록. kinetics/순서/경로/미평형 가설 연쇄 기각 →
    진짜 ΔKH(tank 알칼리니티 < ref, 널 degrade) 유력. 다음=신선 해수 널.
    [measure_kh_once.py]
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2026-06-22 학술체·용어 일관성 교정 (EN/KO)
    EN: 비격식 표현을 학술체로 — (bonus)→additionally, crushed→reduced,
    flip the sign→reverse, head-started→started from a higher initial pH,
    baked into→embedded in calibration, "What the diagnosis bought"→"Implications
    of the error decomposition", goes one further→extends this further,
    share one box of air→share a single common air volume, the fix→the remedy,
    manage by→are managed by, real gap→genuine gap, 현수수식어 정리.
    KO: 음차 차용어를 학술 한국어로 — 룩백→이력 구간, latch→확정, gap→격차,
    dip→강하, 스왑→교체, 웜업→예열, 파킹→임시 보관, kinet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
2026-06-22 구성도 수정: Air1/Air2 라벨 제거 + 참조수 폭기를 위즈 탱크 직접 표현
    - 동시 폭기로 바뀌어 Air1/Air2 구분 라벨 삭제
    - 에어 점선을 수조물 비이커 → 위즈 탱크(참조수 5L) 직접 폭기로 재배선
    - system-setup.svg·setup-demo.svg 동일 적용 + 범례 갱신
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2026-06-25 fix(reefcore): MQTT 발행 retain=False — 유령 중복 레코드 방지
    '최근 측정값'은 수신 시 레코드를 생성하는 이벤트 토픽이라 retain=True면
    브로커 보관본이 백엔드 재접속마다 재전달돼 중복 레코드가 생길 수 있다.
    백엔드는 상시 접속(/debug/state mqtt_connected:true)이라 retain=False도
    발행이 정상 도달한다(retain=True 9.99·retain=False 9.88 둘 다 즉시 반영 실측).
    - measure_kh_once.py:197, reefcore_bridge.py:57 → retain=False
    - 회귀테스트 58 PASS, C:\dkh\work 배포
    - 문서 정정: REST POST /devices/{mac}/measurements 실재(향후 대안),
    /mqtt/acl 훅·/debug/state 무인증 개방 사실 기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
    [measure_kh_once.py, reefcore_bridge.py]
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2026-06-29 fix(reefcore): paho-mqtt CallbackAPIVersion.VERSION2 명시 — DeprecationWarning 제거
    콜백 미등록(publish 전용)이라 기능 영향 없음, paho 1.x는 AttributeError 폴백
    [measure_kh_once.py]
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2026-07-01 fix(pages): 서비스워커를 전면 네트워크 우선으로 전환
    index.html을 캐시 우선으로 서빙해서 배포 후에도 브라우저가 예전 화면을
    계속 보여주는 문제가 실제로 발생(2026-07-01, #plateau 링크 추가 후
    사용자가 못 봄). 그래프/최신값에만 적용하던 네트워크 우선 정책을 앱 셸
    전체로 확장 — 캐시는 오프라인일 때만 대체로 쓴다. 캐시명 v2→v3.
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2026-07-03 fix(measure): BT 장기 링크 사망 대응 3종 (7/2 21시 좀비 사후)
    - write_timeout=5: 반열림 BT COM 쓰기 무한 블로킹(좀비)을 예외로 전환
    - 평탄 phase 중 링크 사망 시 FAIL_MAX 포기 대신 phase 마감까지 60s 간격
    재접속 대기(_wait_link_recovery) — 복구되면 측정 재개
    - 링크 사망으로 calkh/정리 불능이어도 phase 데이터가 온전하면 호스트가
    동일 차동식으로 dKH 계산해 음수 표식 기록·발행(0.0 래치 회피).
    링크 생존 상태의 장비 문제(KCl 소크 실패 등)는 기존대로 0.0 래치
    - 시뮬레이터: [18] 호스트 구제, [19] 링크 복구 재개 시나리오 추가,
    fake_seria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
    [measure_kh_once.py, test_measure_sim.py]
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2026-07-03 fix(measure): tank 평탄 MIN_N=20 도입 — 무딘 S커브 초기 lag false lock 차단
    7/3 05:00 tank dKH 7.509 스파이크(참값 ~7.24) 사후. 평형 접근은 지수라
    기울기∝진폭 — 저진폭 날(새벽, 수조수 pCO₂≈헤드스페이스)은 S커브가 무뎌져
    초기 lag(측정계 과도 포함)가 net8 창 감지한계 밑으로 깔려 조기 잠금.
    낮 런은 첫 8샘플 이동 15~22mpH(여유 15배), 새벽은 3~4mpH(3배), 7/3은 0.
    - FLAT_MIN_N_TANK=20: tank 유효샘플 20회(≈13분) 전 평탄 잠금 금지(보류 로그).
    ref 는 능동폭기 앵커(진폭 0, 8~15회 잠금 정상)라 미적용.
    - firmware_sim: tank_profile 시계열 모드(무딘 S커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
    [firmware_sim.py, measure_kh_once.py, test_measure_sim.py]
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2026-07-06 fix: sync rebase에 --autostash — 작업 중 미커밋 변경에도 동기화 진행
    WSL 저장소에서 사람이 작업 중(커밋 전 변경 존재)이면 rebase가 거부돼
    sync가 사이클을 통째로 건너뛰었다(7/6 13:54 실제 발생 — 대시보드가
    반나절 옛 데이터로 남음). autostash로 stash→rebase→자동 복원.
    더러운 트리 재현 테스트로 rebase 통과·변경 보존 검증.
    [sync_dkh_dat.py]
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2026-07-08 fix: 도저 조정 실패 진단 보강 — 래퍼가 exit≠0 시 자식 출력 꼬리 기록 + log() 파일 기록 우선
    7/8 13:41 권고 실패가 로그·이력 무흔적으로 exit=1만 남아 원인 유실된 건의 재발 대비.
    ① run_measure_and_sync.py: doser 실패 시 stderr+stdout 꼬리(8줄/1000자)를 sync_trigger.log에 남김
    ② doser_adjust.py log(): 파일 기록을 print보다 먼저 + print 예외 무시(인코딩 예외로 기록 유실 방지)
    측정 로직(measure_kh_once.py) 무수정. 배포본 재복사 완료, 드라이런·print예외 생존 검증 완료.
    [doser_adjust.py, run_measure_and_sync.py]
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2026-07-10 fix: 비상정리 전제조건(airoff·ton) 우선 + reconnect 출력버퍼 purge (7/9 21시 사후)
    7/9 21시 무선 콤보칩 장애(2h 링크 사망) 사후 보강 2종:
    - _safe_cleanup: airoff·ton 실패(링크 사망) 시 CLEANUP_RECOVERY_SECS(30분)까지
    재접속을 기다려 전제조건부터 재시도, 끝내 실패하면 모터 생략.
    밀폐계라 airoff·ton 없이는 모터가 돌아도 액체가 안 움직임('완료' 응답≠이송
    성공 — 사용자 라인 검증: m3 라인 건조=KCl 미복원, 로그는 거짓 성공).
    - reconnect(): close 전·open 직후 reset_output_buffer — 사망 중 고인 미송신
    바이트가 복구 직후 지연 배달·실행되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
    [measure_kh_once.py, test_measure_sim.py]
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2026-07-10 fix: 비상정리 진행 지점 판단 선행(_liquid 추적) — 상태별 레시피·위치 불명 시 동결
    사용자 원칙(7/10): 에러 복원은 액체가 어디까지 갔는지 판단이 선행돼야 하며,
    판단 불가면 자동 정리보다 BT 복원 대기 후 이어가기 또는 에러 동결이 낫다.
    - _liquid(chamber/holding) 진행 상태 추적: _move_liquid 가 이동 성공 시점마다 갱신,
    이동 도중 실패(예외·완료 미수신)=UNKNOWN sticky
    - _safe_cleanup 상태별 레시피: KCl=조치 불필요 / tank수=m2b→m1b→m3f(현행) /
    ref수=m4b 5L 순환회수→m1b→m3f / UNKNOWN=모터 생략+동결+★★경고
    (기존 고정 레시피는 시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
    [measure_kh_once.py, test_measure_sim.py]
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2026-07-16 fix: 윈도우 업데이트 BT COM 포트 재배치 대응 (측정기 COM9→COM14, 도저 COM12→COM15)
    7/16 윈도우 업데이트 재부팅으로 BT SPP 포트 재열거:
    - HC-06 측정기(98DA600FC57A): COM9→COM14
    - 도저(98DA60056895): COM12→COM15
    스케줄 작업 '블루투스 시간 설정' 인자도 COM15로 변경, 배포본 복사 완료.
    시뮬 117 PASS + CO2 플래그 46 PASS, 양 포트 실연결 검증 완료.
    [bt_health.py, doser_adjust.py, measure_kh_once.py]
2026-07-16 fix: 도저 권고 테이블 중단(abort) 행 예외 원문 오버플로 수정
    7/16 13시 COM 실패 abort 항목의 note(파이썬 예외 덤프)가 도징 칸에
    그대로 출력돼 표가 카드 밖까지 넘침. 셀에는 첫 콜론 앞 짧은 사유만
    표시(예: 'COM12 연결 실패 — 변경 없음'), 원문은 행 title 툴팁 유지.
2026-07-16 fix: 도저 권고 테이블 중단 행 도징 칸에 사유 대신 (변경 없음)만 표시
    도징 칸은 양 표시용이라 실패 사유가 들어갈 자리가 아님(사용자 지적).
    사유 원문은 행 title 툴팁으로만 유지, 모드 열의 '중단' 배지가 실패를 알림.
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2026-07-23 docs: 측정 방식 개선(고정 사전폭기+노이즈 차단 측정) 문서 반영
    커밋 09390d5(측정 코드 변경)를 사이트 문서에 반영:
    - system-setup: 측정 원리(폭기 중→하이브리드)·흐름도 사전폭기 단계·상수표
    (FLAT_MIN_N_TANK 0, PHASE_MAX 5400, MEAS_MAX 180, 신규 PREAERATE_SECS/SETTLE_SECS)
    ·소요시간·ExecutionTimeLimit·시뮬 23/122
    - bt-reconnect-and-testing: 시뮬 23/122, 시나리오표 [20] 재서술 + [21][22][23] 추가
    - user-manual §3.2·§8.1, README: 측정 원리 문구 하이브리드로
    - measurement-ledger: 7/23 측정 방식 개선 섹션 추가(이력 append)
    - README: measure_kh_once 포트 주석 stale 수정(COM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
2026-07-24 feat(measure): ron 재폭기 유실 감지·자가치유·경고(ensure_aeration_on)
    7/23 per-read 폭기 토글 도입 후, ron(재폭기) 응답이 조용히 유실되면
    편향이 흔적 없이 발행되는 은닉 경로가 있었다:
    - send()는 '참조ON' 미수신 시 SEND_RETRY_MAX 재시도 후 예외 없이 조용히
    (부분)리턴하는데, ron 호출부 3곳이 반환값을 안 봤다(루프=try/pass, 사전폭기=bare).
    - 특히 사전폭기 직전(773 tank·796 ref) 유실 시 25분/3.5분 사전폭기 전체가
    폭기 없이 흘러 미평형 편향이 조용히 dKH로 발행·도저 전파.
    수정(작은 수정 큰 효과, 발행/dkh.dat 계약 불변):
    - ensure_aeration_o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
    [firmware_sim.py, measure_kh_once.py, test_measure_sim.py]
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2026-07-24 feat(doser): 대시보드 0=정지(lrt 0) + 단순 UI
    - doser_adjust.py: plan_lrt() 추가 — 0=정지(lrt 0, 무배출), 양수는 2000~24000ms
    클램프, (0,1.5)는 방어적으로 하한. apply_manual_override 가 사용. auto/gap 로직 불변.
    - index.html: 도징량 입력 0 허용·검증(0 또는 1.5~18), 정지 상태 표시(현재도징·실도징·
    저장확인·대기), 설정 문구 갱신.
    - test_co2_flag.py: [7] plan_lrt 회귀 10건, [2] EXPECTED_SUSPECT 재기준화(7/18·19·22
    확정 편향런 4개, dkh_series co2_suspect 교차확인). 56 PASS / 0 FAIL.
    정지 메커니즘으로 gap 확대 대신 lrt 0 채택: lgt 확대는 SimpleTimer(millis 32bit)
    롤오버(49.7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
    [doser_adjust.py, test_co2_flag.py]
2026-07-24 fix(firmware): 롤오버 시 도징/토출 타이머 밀림 제거 (도저 + 폭기 분배기)
    ca_reactor_output_controller_v8 · air_pump_distributor_v3_0 공통:
    loop() 의 millis() 롤오버(≈49.7일) 처리에서 refresh_all_timers() 호출을 제거한다.
    SimpleTimer.isReady() 는 (millis()-_previous)>=interval 을 부호 없는 32비트 뺄셈으로
    비교하므로 롤오버를 스스로 정확히 넘긴다. 롤오버마다 타이머를 리셋하면 진행 중이던
    GAP 카운트다운이 버려져 ~49.7일에 1회 도징/토출이 최대 1주기 늦춰지는 밀림이 있었음.
    setup()·"refresh all" 명령에서의 호출은 필수라 유지, Diff_Time(로그 시각) 보정 유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
2026-07-25 fix(firmware): 측정기 I2C(ADS1115) 무한대기 행 복구 + WDT 안전망 + [RAW] 진단
    측정기 아두이노가 ADS1115 I2C 읽기(readADC_SingleEnded 의 while(!conversionComplete()),
    타임아웃 없음)에서 신호선(SDA/SCL) 접촉 상실 시 무한 대기 → loop 정지 → 완전 무응답
    (2026-07-24 8시간 침묵). A4(=SDA) 뽑기로 실측 재현·확정.
    - readADSsafe(): ADS 변환 400ms 상한
    - recoverI2C(): SCL 9펄스 언스틱 → Wire.begin → ads.begin 재초기화, Wire.setWireTimeout(25ms)
    - 부팅 while(1) 제거(bounded 재시도), WDT 8초 안전망(부팅 wdt_disable 로 부트루프 방지)
    - 연속 24회 실패 시 측정 중단(펌웨어 응답 유지)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
    [aquawiz_ph_meter_final.ino, firmware_sim.py]
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2026-07-27 fix: 도저 정지(0) 유지 가드 + 측정 시작 시 settime:HH 주입
    ① compute() 정지 가드: lrt 0(대시보드 수동 정지)일 때 step_cap=0 에 걸린 값이
    LRT_MIN(2000ms) 하한에 끌려 올라가 "멈춘 도저를 재가동" 하는 권고가 나왔다
    (7/25~7/27 로그, dKH 는 목표보다 0.7 높은 상황). 자동 경로는 0 을 그대로 두고
    재개는 대시보드 수동 설정으로만. 목표 미만이면 정보성 note 만 덧붙인다.
    AUTO_APPLY=True 로 재개할 때 정지가 저절로 풀리는 사고 방지.
    ② 측정 시작 시 settime:HH 송신: 펌웨어가 이미 지원하는 명령을 호스트가 한 번도
    보내지 않아 calkh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
    [doser_adjust.py, firmware_sim.py, measure_kh_once.py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]
2026-07-28 fix: airoff(폭기 OFF) 응답 확인 추가 — ron 대칭, 조용한 유실 가시화
    send() 는 응답 미수신을 예외 없이 조용히 리턴하므로, ron 방향(2026-07-24
    ensure_aeration_on)과 달리 airoff 는 반환값을 아무도 보지 않아 유실이 무흔적이었다.
    유실이 남기는 결과는 지점에 따라 다르다:
    - read 직전 유실 → 폭기 켜진 채 read = 모터 노이즈·버블 산란(구 스킴 품질로 하락)
    - 액체 이동 직전 유실 → 밀폐계라 이송 무효인데 모터 '완료' 는 정상 수신 = 거짓 성공
    (7/9 21시 사고와 같은 실패 모드)
    ensure_aeration_off(ser, where, swallow=True) 신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
    [measure_kh_once.py, test_measure_sim.py]
2026-07-28 fix: 액체 이동 전제조건 필수화(거짓 성공 차단) + ★★경고 게이팅 통일
    사용자 지시(2026-07-28): "거짓 성공은 있으면 안 된다", "ron 도 통일".
    1) 이송 전제조건 필수 — ensure_move_precond 신설
    밀폐 공통 헤드스페이스라 airoff·ton 없이 모터를 돌리면 액체가 안 움직이는데 모터
    '완료' 응답은 정상으로 온다 = 거짓 성공(7/9 21시 실증). 비상정리는 2026-07-10 에 이
    원칙을 이미 갖췄으나(_cleanup_precond) 본 흐름의 이송 3곳은 airoff·ton 응답을 아무도
    확인하지 않아 같은 실패 모드가 남아 있었다. ton 무확인도 여기 포함(airoff 만의 문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
    [measure_kh_once.py, test_measure_sim.py]
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2026-08-13 refactor: 측정 소스에서 reefCore 자동 발행 제거
    measure_kh_once.py 가 dkh.dat 기록 직후 MQTT 로 reefCore(reefChecker)에
    측정값을 발행하던 경로를 전부 제거한다(사용자 지시).
    - publish_to_reefcore()·_reefcore_creds()·_publishable() 삭제
    - 호출 3곳 제거: 정상 결과 기록 후 / 에러 표식(0.0) 기록 후 / 에러 래치 경로
    - 측정은 dkh.dat 기록까지만 수행. reefcore.conf·paho 설치와 무관해짐
    - bin/reefcore_bridge.py(수동 1회 발행 도구)는 유지 — 필요 시 직접 실행
    회귀 검증: cd bin && python3 test_measure_sim.py → 146 PASS / 0 FAIL
    발행을 검증하던 시나리오([13][14][15][16][17][18])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
    [measure_kh_once.py, test_measure_sim.py]
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2026-08-30 firmware: FW_COMMIT 을 앞 커밋(55dafc5) 코드로 확정
    기기 버전의 # 뒤 커밋코드를 식별 규약을 도입한 커밋 55dafc5 로 맞춘다.
    3종 모두 재컴파일 확인(크기 변화 없음).
    ReefWiz Meter M-1 v1.0.0 #55DAFC
    ReefWiz Doser D-1 v1.0.0 #55DAFC
    ReefWiz Air A-1 v1.0.0 #55DAFC
    이후 펌웨어 소스를 고치면 플래시 직전 `git rev-parse --short=6 HEAD`
    값(대문자)으로 FW_COMMIT 을 갱신한다(각 소스 상단 주석에 명시).
    [reefwiz_air_a1.ino, reefwiz_doser_d1.ino, reefwiz_meter_m1.ino]
